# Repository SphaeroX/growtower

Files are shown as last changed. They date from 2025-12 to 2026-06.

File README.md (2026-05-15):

# GrowTower

A minimalist, vertical grow tower designed for home cannabis cultivation. This project focuses on space efficiency, ease of use, and effective odor control, making it perfect for beginners and small living spaces.

## Features

- **Vertical Grow System:** Maximizes vertical space usage.
- **Integrated Odor Control:** Features a custom-designed activated carbon filter housing.
- **Silent & Efficient Cooling:**  Uses a standard Arctic P14 generic PC fan for both airflow and cooling.
- **Web-based Control:** Control your GrowTower from any browser at `http://growtower.local` - no app required!
- **Automatic Light Timer:** Configurable 24h light schedule with web interface.
- **Minimalist Design:** clean aesthetics that blend into a modern home environment.
- **Beginner Friendly:**  Simple assembly and maintenance. Hard to make mistakes.
- **3D Printable:**  Most structural components are designed to be 3D printed.
- **Odor-Free Drying:** Convert the tower into a drying chamber after harvest using the included Dryer Module, utilizing the carbon filter.

## Gallery

| | | |
|:---:|:---:|:---:|
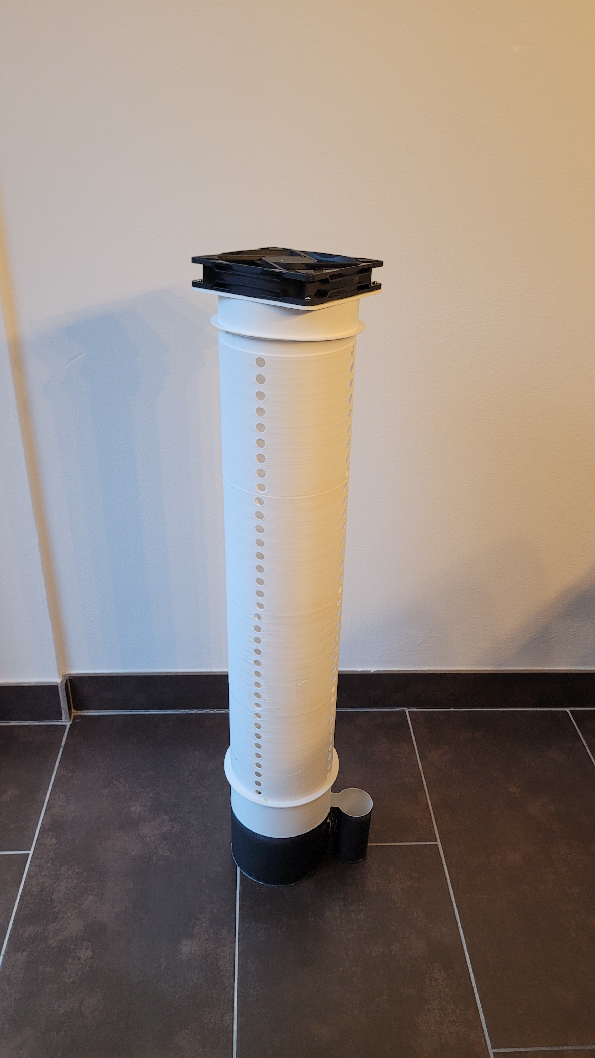
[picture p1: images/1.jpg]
View 1
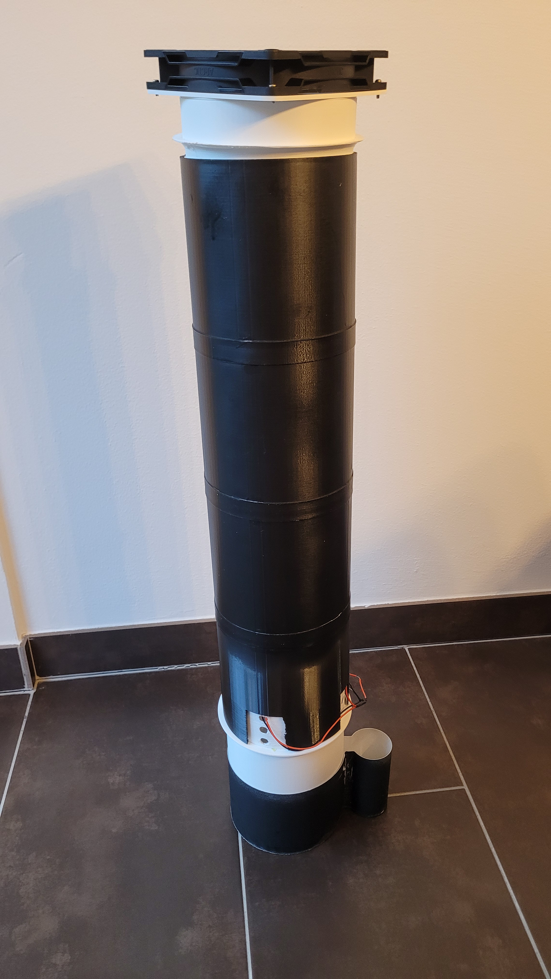
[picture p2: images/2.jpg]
View 2
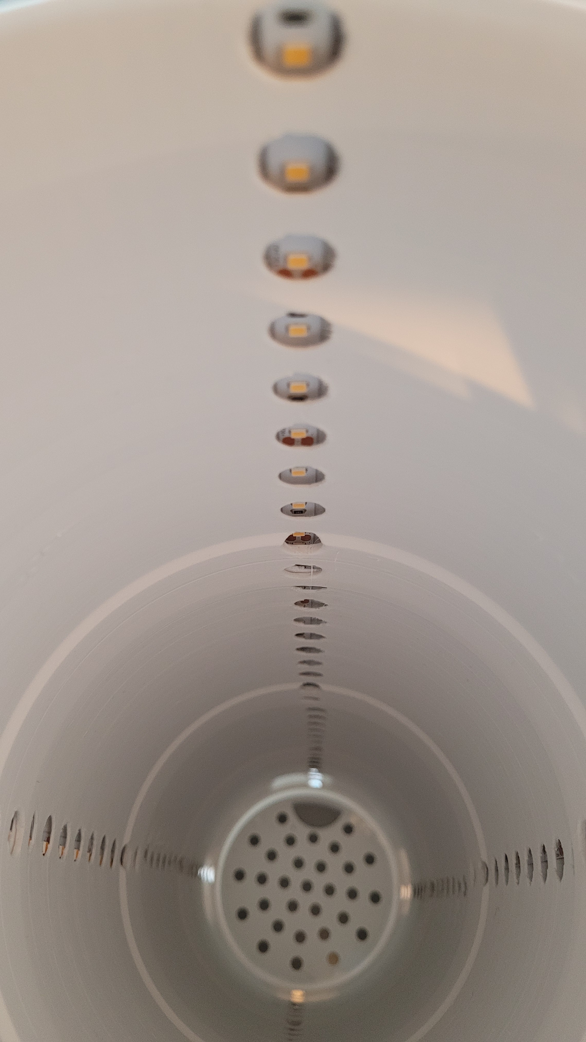
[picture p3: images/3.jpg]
View 3
|  |  |  |
| *Front View* | *With Light Chamber* | *Inside* |

### Controller & Electronics

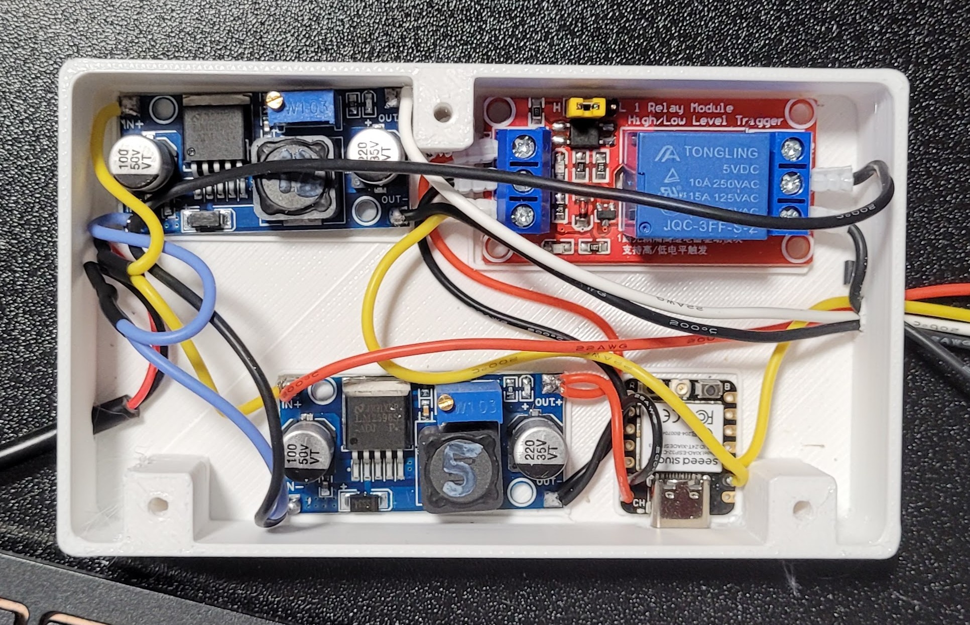
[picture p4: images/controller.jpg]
Controller

*Wired ESP32 Controller with Fan, Light Relay and Power Supply*

## How it Works

The GrowTower utilizes a forced-air system where the Arctic P14 fan pulls air through the tower, ensuring fresh CO2 for the plant and maintaining optimal temperatures. The air is then pushed through an activated carbon filter before exiting, neutralizing any odors. The vertical stacking design allows for modularity and easy height adjustment as the plant grows.

## Growing System

The GrowTower is designed for a **Full-Hydroponic Wick System** (using Pumice) or a **Semi-Hydroponic** setup. It utilizes passive irrigation to provide precise moisture control while maintaining high aeration for the roots.

For detailed, step-by-step instructions on the recommended **12/12 One-Bud method**, please refer to the [**GROW_GUIDE.md**](GROW_GUIDE.md).

## Drying after Harvest

With the included **Dryer Module** (STL), the GrowTower can easily be converted into an odor-free drying chamber. The module is simply inserted between the top Inner Shell and the Filter Housing. You can hang and tie your harvested plant directly to this module. The active carbon filter ensures that the entire drying process remains completely odorless.

## Getting Started

1. **Build your Tower:** See [BOM.md](BOM.md) for a full list of materials required.
2. **Follow the Grow Guide:** Use the [**GROW_GUIDE.md**](GROW_GUIDE.md) as your primary resource for successful cultivation. It contains the complete timeline, nutrient dosages, and substrate setup.
3. **Setup Controller:** Flash the ESP32 with the firmware from the `firmware/` directory. See [firmware/README.md](firmware/README.md) for details.

## Web Controller

The GrowTower includes a built-in web server for easy control via WiFi:

- **Access:** Open `http://growtower.local` in any browser after connecting to WiFi
- **Features:**
  - Real-time status dashboard (light, fan, timer)
  - Manual light control (ON/OFF)
  - PWM fan speed adjustment (0-100%) with configurable min/max range
  - 24-hour light timer with automatic scheduling
  - Configurable device hostname (e.g., `mytower.local`)
  - REST API for custom integrations

## 3D Printing Instructions

All STL files and detailed printing instructions are located in the [`stls/`](stls/) directory. This includes material recommendations, slicer settings, and assembly instructions. For detailed post-processing (light-proofing), see [`stls/README.md`](stls/README.md).

## Troubleshooting

### Light is blinking every second
If the main light is blinking in a 1-second interval, the controller **cannot synchronize the time** (no internet connection). Since the light timer depends on the current time, the controller enters this safety/warning mode.
- **Solution:**
  1. Connect your phone/PC to the WiFi network `GrowTower-Fallback`.
  2. Open `http://192.168.4.1` in your browser.
  3. Go to the settings and update your WiFi credentials (SSID & Password).
  4. Alternatively, you can manually set the current time via the API to enable offline operation.

### Cannot reach `growtower.local`
- Ensure you are on the same WiFi network as the GrowTower.
- Try accessing it via the IP address shown in the Serial Monitor.
- Some Windows systems require "Bonjour" or "iTunes" installed for `.local` (mDNS) support.

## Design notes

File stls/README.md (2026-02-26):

# 3D Printing Instructions

This directory contains all STL files for the GrowTower project.

## General Printing Recommendations & Materials

- **Main Material:** PETG White (highly recommended for the main body). The white color is crucial on the inside to maximize light reflection for the plant.
- **Exceptions (Black Material):** The Filter Components, Plant Pot, and Water Reservoir can and should be printed in **Black PETG** (or another dark opaque color). This prevents light from reaching the roots and water, which would otherwise encourage algae growth.
- **Light-Proofing (Crucial Step):** The white outer shell **must** be light-proofed from the outside. This is a critical physical requirement to prevent external light from disrupting the plant's light cycle (especially important for photoperiod strains in Grow #2). 
  - **Method 1 (Recommended):** Coat the fully assembled white outer shell from the outside using black spray foil / liquid rubber (e.g., PlastiDip). This ensures a light-tight seal by filling microscopic 3D printing gaps and offers better thermal elasticity.
  - **Method 2:** Wrap the outside tightly in a black, light-blocking foil or tape.
  - *Note:* The inside of the shell must remain white for maximum light reflection!
- **Nozzle:** 0.6mm recommended (faster printing, sufficient precision)
- **Support:** Generally not required for most parts

---

## Plant Pot Printing Instructions

The plant pot is 100mm tall. For optimal results without supports, the pot can either be printed **solid in one piece** or **cut at 49.7mm** and glued together:

### Option 1: Print Solid (Recommended for seamless result)
- Print the entire pot in one piece
- No cutting or gluing required
- May require minimal support for the rim

### Option 2: Cut and Glue (Saves support material)
1. **Cut the Pot:** In your slicer, use the cut tool to split the pot horizontally at **49.7mm** (exactly half).
2. **Print Both Parts:** 
   - **Upper part:** Print as oriented in the STL (no change needed)
   - **Lower part:** Rotate so the cut face sits flat on the print bed
3. **Glue Together:** After printing, glue the two halves together using super glue or epoxy. Align the seams carefully for a clean joint.

The cut method saves support material since each half prints flat without supports.

| | |
|:---:|:---:|
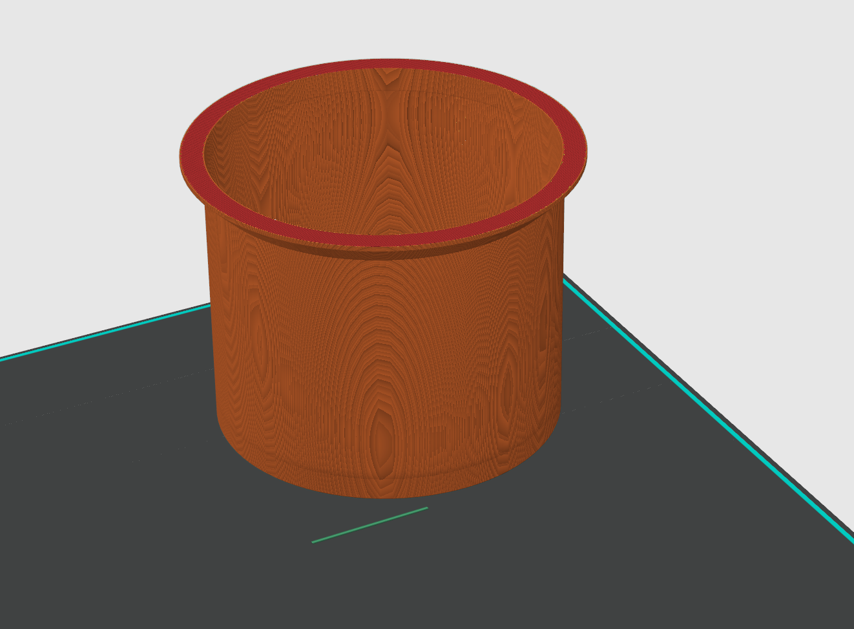
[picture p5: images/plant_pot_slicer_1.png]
Plant Pot Cut 1
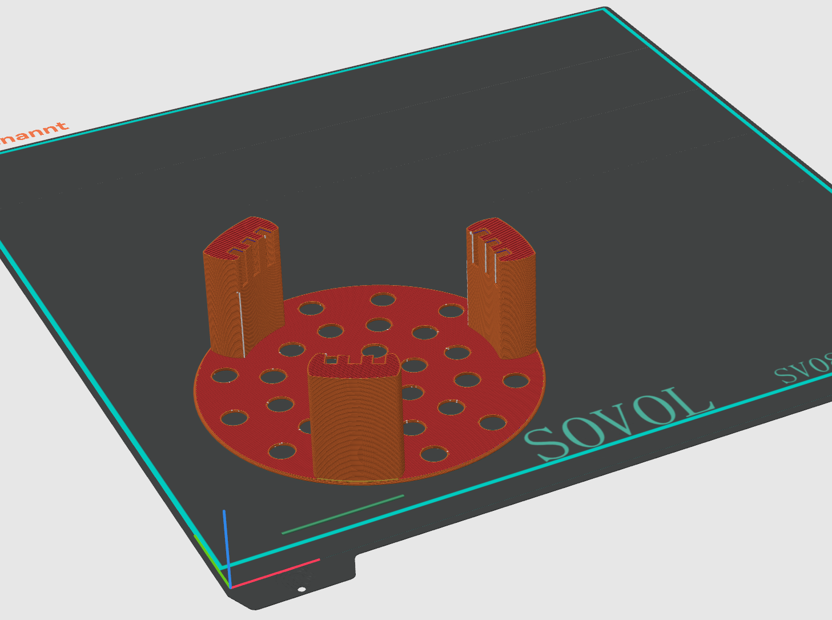
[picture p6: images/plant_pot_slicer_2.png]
Plant Pot Cut 2
|  |  |
| *Plant Pot Upper* | *Plant Pot Lower* |

---

## Internal Sieve Printing Instructions

The Internal Sieve model is intentionally designed to be "closed". To print it correctly:

1.  **Open the Sieve:** In your slicer, use a modifier to remove the top and bottom solid layers.
2.  **Create the Mesh:** Set the infill density to approximately **30%** and use a **Rectilinear** pattern. This generates the necessary mesh structure for the filter.

| | |
|:---:|:---:|
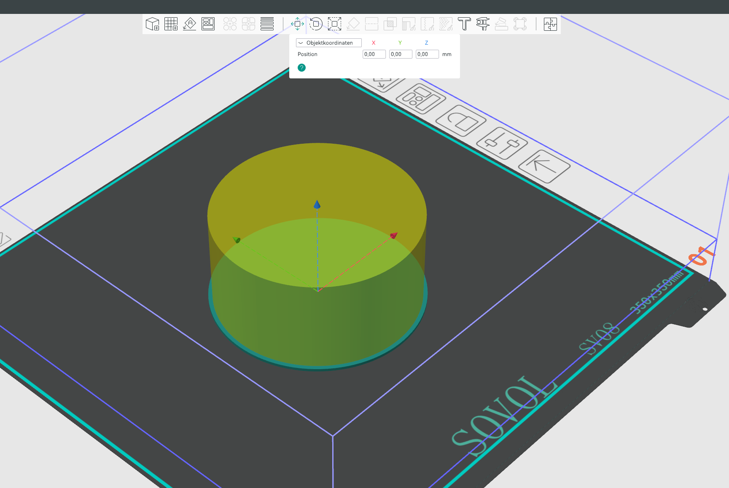
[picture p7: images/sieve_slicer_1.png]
Slicer View 1
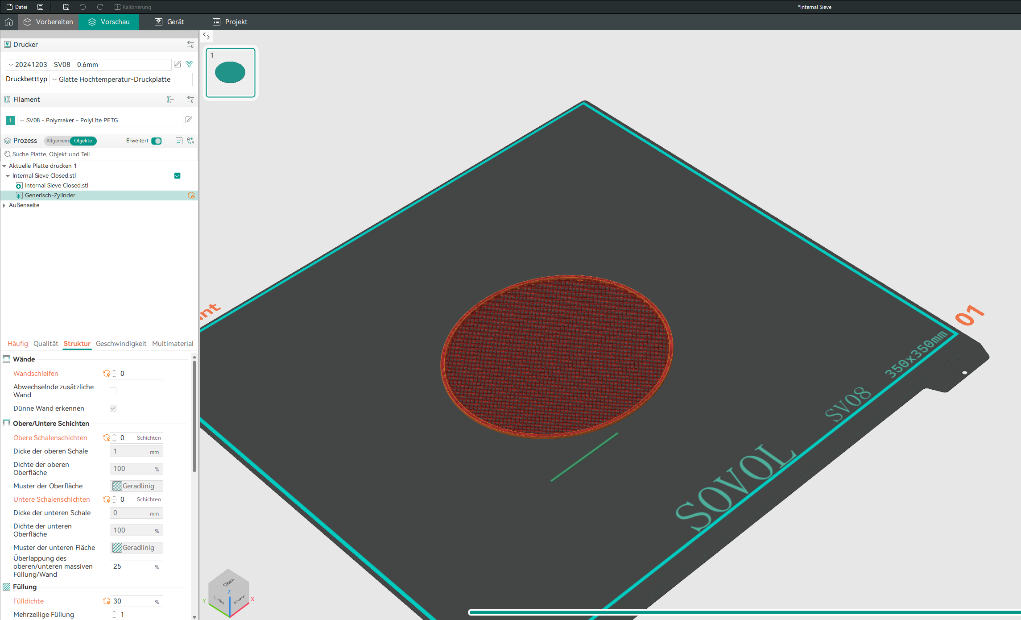
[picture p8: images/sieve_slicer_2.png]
Slicer View 2
|  |  |
| *Sieve View 1* | *Sieve View 2* |

---

## Reservoir 850 Vase Printing Instructions

**File:** `Reservoir 850 vase.stl`

For optimal printing results and watertightness, use these settings:

1. **Vase Mode:** Enable "Spiralize" or "Vase Mode" in your slicer.
2. **Bottom Layers:** Use at least **4 bottom layers** for a stable and leak-proof base.
3. **Pattern Design:** Ensure the upper pattern differs from the lower pattern to create a distinct transition and visual appeal.
4. **Layer Height:** Use a **small layer height** (e.g., 0.1-0.2mm) to ensure the print is watertight.
5. **Flow Rate:** Increase flow rate by at least **5%** compared to your standard settings for better layer adhesion and watertightness.
6. **Ironing:** Enable ironing to re-weld the top layer for a smoother and more sealed surface.
7. **Infill/Wall Overlap (OrcaSlicer):** Set BOTH values to **40% to 50%**:
   - `InfillWall-Overlap`
   - `infill-wall-overlap`

### Troubleshooting Leaks

- **Water Test:** Always perform a water test before using the reservoir to check for leaks.
- **Common Issue:** Pay special attention to the transition from the bottom to the walls, as this is where leaks most commonly occur.
- **Repair:** If leaks are found at the bottom-wall transition, they can often be fixed by welding the spots with a soldering iron. Don't give up - somehow it can always be made watertight!

## Dryer Module Printing Instructions

The Dryer Module (Trocknungsmodul) is an optional insert used after harvest. It allows you to hang the harvested plant inside the tower for drying.

- **Function:** Fastening points are provided to tie the plant securely for drying.
- **Placement:** Insert the module simply between the top Inner Shell and the Filter Housing.
- **Printing:** Standard settings (15-20% infill). Can be printed in any color, though Black or White PETG is recommended to match the tower.
- **Benefit:** By drying inside the GrowTower, the active carbon filter continues to neutralize all odors during the drying process.

---

## Other Parts

The remaining parts (Inner Shell, Outer Shell, Outer Shell Bottom, Shell Connector, Filter Housing, Fan Adapter) can be printed with standard settings:

- **Infill:** 15-20%
- **Supports:** Not required
- **Orientation:** Print as oriented in the STL file

### Outer Shell Assembly

The outer shell consists of **3x Outer Shell** + **1x Outer Shell Bottom**, connected with **3x Shell Connector**:

**Printing Options:**
- **Standard Print:** Print with normal settings (15-20% infill, walls as normal)
- **Vase Mode (Faster):** Print in vase/spiralize mode for faster printing. Note: You'll need to orient the LED strips carefully after printing to ensure even light distribution. When printed in vase mode, a small bump remains visible on the inside - use this as your orientation marker for LED strip alignment.

| | |
|:---:|:---:|
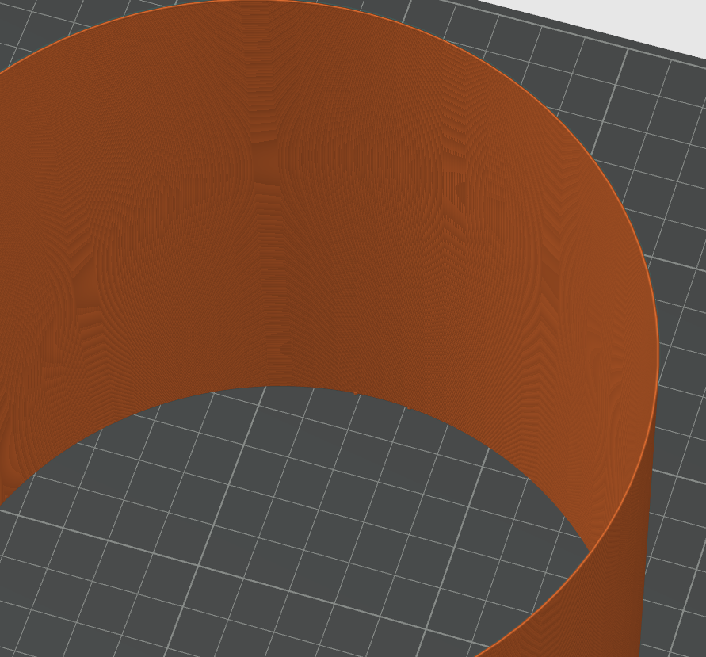
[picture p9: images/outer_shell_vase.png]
Outer Shell Vase
|  | *Visible bump for LED orientation* |

**Assembly:**
1. **Print:** Print 3x Outer Shell and 1x Outer Shell Bottom, plus 3x Shell Connector
2. **First Connector:** 
   - Apply a small amount of glue to the connector and position it on the first Outer Shell section
   - Apply glue all around the connector where it overlaps with the shell
   - Push the connector down so it slides onto the glue - this ensures the 50% overlap
3. **First Shell Section Complete:** Let the glue fully cure before continuing (otherwise it will slip)
4. **Add Second Shell:**
   - Apply a small amount of glue to the connector and pre-mount the next Outer Shell section
   - Apply glue all around the connector
   - Push the second shell down onto the connector
5. **Repeat:** Continue the same process for all remaining Outer Shell sections
6. **Attach Bottom:** Finally, attach the Outer Shell Bottom at the base using the same method

The Shell Connector is a ring that overlaps 50% with each shell, creating a secure slip-fit joint between sections.

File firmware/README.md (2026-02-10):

# GrowTower Firmware

This directory contains the ESP32 Arduino-based firmware for the GrowTower, designed for the **Seeed Studio XIAO ESP32C3** (configured as `seeed_xiao_esp32c3` in PlatformIO).

## Features

- **Web-based Control**: Access the controller via any web browser at `http://growtower.local`
- **REST API**: HTTP endpoints for all control functions
- **mDNS Support**: Automatic discovery via `*.local` domain (configurable hostname)
- **Real-time Status**: Live updates of system state in the web interface
- **OTA Updates**: Over-the-air firmware updates via PlatformIO
- **Automatic Timer**: Light scheduling with configurable on/off hours
- **Fan Control**: PWM-based speed control with configurable min/max range
- **Persistent Settings**: All configuration stored in flash memory

## Prerequisites

- **VS Code** with **PlatformIO** extension installed.
- OR **PlatformIO Core** (CLI) installed.

## Configuration

Settings are managed via a local `.env` file (ensuring credentials are not committed to git).

### 1. WiFi Credentials (.env)

You **MUST** create a file named `.env` in the `firmware/` directory. This file is used to generate `secrets.h` before every build.

**Example `firmware/.env` content:**
```ini
WIFI_SSID="YourWiFiName"
WIFI_PASS="YourSuperSecretPassword"
```
*Note: This file is ignored by git.*

### 2. Pin Definitions

Pin definitions are located in `src/main.cpp`.

By default:
- **Light Relay**: GPIO 1 (D1)
- **Fan PWM**: GPIO 4 (D2)

### 3. Hostname Configuration

The default hostname is `growtower`. You can change it via:
- **Web Interface**: Settings → Device Name
- **Serial Command**: `HOST <newname>`

After changing, the device will restart and be available at `http://<newname>.local`

## Building and Flashing

Open your terminal in this directory (`growtower/firmware`).

### 1. Build

Compiles the firmware:

```powershell
pio run
```

### 2. Flash (USB)

Uploads firmware via USB:

```powershell
pio run -t upload
```

*Note: If the upload fails, ensure the device is in bootloader mode (hold BOOT, press RESET, release BOOT).*

### 3. Flash (OTA - Over The Air)

Uploads firmware wirelessly (after initial USB flash):

```powershell
pio run -t upload -e main_ota
```

Or specify the hostname/IP:
```powershell
pio run -t upload --upload-port growtower.local
```

### 4. Monitor

Opens the serial monitor for debugging:

```powershell
pio device monitor
```
*Note: Exit with `Ctrl+C`.*

## Web Interface

Once connected to WiFi, open your browser and navigate to:

```
http://growtower.local
```

### Features

- **Dashboard**: Real-time status of light, fan, timer settings
- **Light Control**: Turn light ON/OFF manually
- **Fan Control**: Adjust speed (0-100%) and set min/max range
- **Timer Settings**: Configure automatic light schedule (24h format)
- **Network Settings**: Change device hostname (requires restart)

The interface automatically updates every 2 seconds and is optimized for both desktop and mobile devices.

## REST API

All functions are accessible via HTTP GET requests:

| Endpoint | Parameters | Description |
|---|---|---|
| `GET /api/status` | - | Returns JSON with all current values |
| `GET /api/light` | `state=0\|1` | Turn light OFF (0) or ON (1) |
| `GET /api/fan` | `speed=0-100` | Set fan speed percentage |
| `GET /api/fanrange` | `min=0-100&max=0-100` | Set fan min/max range |
| `GET /api/timer` | `on=0-23&off=0-23` | Set light timer hours |
| `GET /api/hostname` | `name=<hostname>` | Change hostname (reboots) |

### Example API Responses

**Status Request:**
```bash
curl http://growtower.local/api/status
```

**Response:**
```json
{
  "light": true,
  "fan": 30,
  "fanMin": 0,
  "fanMax": 100,
  "lightOn": 18,
  "lightOff": 14,
  "hostname": "growtower",
  "ip": "192.168.1.100",
  "wifiConnected": true,
  "hasTime": true,
  "currentTime": "14:30:25"
}
```

## Serial Console Commands

You can also control the device via serial monitor:

| Command | Description | Example |
|---|---|---|
| `ON` | Turn light ON | `ON` |
| `OFF` | Turn light OFF | `OFF` |
| `FAN <0-100>` | Set fan speed | `FAN 50` |
| `FANMIN <0-100>` | Set minimum fan speed | `FANMIN 10` |
| `FANMAX <0-100>` | Set maximum fan speed | `FANMAX 90` |
| `LIGHTON <0-23>` | Set light ON hour | `LIGHTON 18` |
| `LIGHTOFF <0-23>` | Set light OFF hour | `LIGHTOFF 14` |
| `HOST <name>` | Set device hostname | `HOST mytower` |
| `TIME` | Show current time | `TIME` |
| `STATUS` | Show full status | `STATUS` |
| `RESET` | Reset all settings | `RESET` |
| `HELP` | Show command list | `HELP` |

## Default Settings

After first flash or reset:

- **Light**: OFF
- **Fan Speed**: 30%
- **Fan Range**: 0% - 100%
- **Light Timer**: 18:00 ON → 14:00 OFF
- **Hostname**: growtower

## Troubleshooting

### Cannot access growtower.local

1. Ensure your device is on the same network as the ESP32
2. Try accessing via IP address (check serial monitor for IP)
3. On Windows: Install Bonjour Print Services or iTunes (for mDNS support)
4. On Linux: Ensure `avahi-daemon` is running
5. Some routers may block mDNS - use IP address instead

### Web interface not loading

1. Check WiFi connection in serial monitor
2. Verify the ESP32 got an IP address
3. Try clearing browser cache
4. Check firewall settings

### Upload fails

1. **USB Upload**: Check COM port with `pio device list`
2. **OTA Upload**: Ensure device is online and hostname resolves
3. **Bootloader Mode**: For first flash:
   - Hold `BOOT` button
   - Press and release `RESET`
   - Release `BOOT`
   - Try uploading again

### Settings not persisting

Ensure the ESP32 has enough flash space and isn't being reset during write operations.

## Technical Details

- **Framework**: Arduino (PlatformIO)
- **Platform**: ESP32-C3 (Seeed Studio XIAO)
- **Web Server**: ESPAsyncWebServer
- **mDNS**: ESPmDNS
- **Storage**: Preferences (NVS)
- **OTA**: ArduinoOTA

## Project Structure

```
firmware/
├── src/
│   └── main.cpp          # Main firmware code
├── include/
│   └── secrets.h         # Auto-generated from .env
├── platformio.ini        # PlatformIO configuration
├── .env                  # Your WiFi credentials (gitignored)
└── README.md            # This file
```

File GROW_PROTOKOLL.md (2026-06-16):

# GrowTower: Protocol & Logbook

This protocol serves as a printable logbook to document your current grow using the **12/12 One-Bud method**. Enter the dates and check off the completed steps.

**Start Date (Germination):** ________________________  
**Strain:** ________________________  
**Stated Flowering Time:** ________________________  

---

## Phase Protocol

| Phase / Timeline | Day | Date | Action (Short Format) | Completed / Notes |
| :--- | :--- | :--- | :--- | :--- |
| **Phase 0:**<br>Germination | **Day 0** | | - Soak seed in water for 24-36h<br>- Plant seed, water once with 30ml pH-adjusted water<br>- Light: 18/6-20/4 (see Grow Guide), Fan: 0%<br>- Daily: 2x 3ml via pipette directly to seed spot | |
| **Week 1:**<br>Establishment | **Day 1 - 7** | | - Water only drop by drop via pipette if extremely dry<br>- Fan: 30% | |
| **Week 2:**<br>First Flush | **Day 8 - 10** | | - 1x full watering (800ml pH-adjusted water) from above (until runoff/drain)<br>- Afterwards **do not water at all**, let substrate dry! | |
| **Week 3:**<br>Reservoir | **Day 15 - 21**  | | - **Switch light to 12/12!**<br>- Pour out old flush water completely first!<br>- Fill reservoir to 20-30% with pure, pH-adjusted water<br>- **Never water from above again!**<br>- Add 50% Hy-Pro Terra dose (~2.0ml per 800ml) — soil nest is depleted, pumice needs feeding | |
| **Week 4-5:**<br>Stretch | **Day 22 - 35**  | | - 75-100% Hy-Pro Terra dose in reservoir (~3.0-4.0ml per 800ml)<br>- Ramp from 3.0ml to 4.0ml by end of phase<br>- Refill reservoir regularly<br>- Watch out for first white hairs (pistils) | |
| **Flowering:**<br>Flower Day 1 | **ca. Day 30** | | - First white hairs spotted = Flower Day 1!<br>- Note the exact date for Flower Day 1 below | |
| **Flowering Phase:**<br>Full Bloom | **FD 1 to End**  | | - Fan: 46%<br>- 100% Hy-Pro Terra: ~4.0ml fertilizer + ~2.3ml pH-Down per 800ml<br>- Optional: 125% peak boost (~5.0ml) mid-flower if no tip burn | |
| **Flushing:**<br>Flush | **Last 14 Days** | | - Stop all fertilizer 10-14 days before harvest<br>- Fill reservoir only with pure, pH-adjusted water | |
| **Harvest** | **-** | | - Cut, dry & cure | |

---

## Important Dates & Milestones

* **Day 1 (Seedling emerges):** ________________________
* **Day 8 (First Flush completed):** ________________________
* **Flower Day 1 (First pistils visible):** ________________________
* **Planned Harvest Date (FD 1 + Flowering Time):** ________________________
* **Start Flushing Phase (-14 days before harvest):** ________________________

---

## Logbook: Nutrient Solution & Measurements

*Rule:* Never let nutrient solution sit in the reservoir for more than 7-10 days (maximum 14 days) to prevent root rot!  
*Recipe (800ml):* ~4.0ml Hy-Pro Terra + ~2.3ml pH-Down (Target pH: 5.8). Add CalMag (0.5-1.0ml/L) every 3rd refill.

| Date | Action (Refill / Change) | Amount Water (ml) | Amount Fertilizer (ml) | pH Measured | Notes (Plant Health / Appearance) |
| :--- | :--- | :--- | :--- | :--- | :--- |
| | | | | | |
| | | | | | |
| | | | | | |
| | | | | | |
| | | | | | |
| | | | | | |
| | | | | | |
| | | | | | |
| | | | | | |
| | | | | | |
| | | | | | |
| | | | | | |
| | | | | | |
| | | | | | |
| | | | | | |
| | | | | | |

---
*Reminder: Once the wick system (reservoir) is active, never water from above again!*

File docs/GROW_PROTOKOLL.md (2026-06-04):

# GrowTower: Protocol & Logbook

This protocol serves as a printable logbook to document your current grow using the **12/12 One-Bud method**. Enter the dates and check off the completed steps.

**Start Date (Germination):** ________________________  
**Strain:** ________________________  
**Stated Flowering Time:** ________________________  

---

## Phase Protocol

| Phase / Timeline | Day | Date | Action (Short Format) | Completed / Notes |
| :--- | :--- | :--- | :--- | :--- |
| **Phase 0:**<br>Germination | **Day 0** | | - Soak seed in water for 24-36h<br>- Plant seed, water once with 30ml pH-adjusted water<br>- Light: 12/12, Fan: 0%<br>- Daily: 2x 3ml via pipette directly to seed spot | |
| **Week 1:**<br>Establishment | **Day 1 - 7** | | - Water only drop by drop via pipette if extremely dry<br>- Fan: 30% | |
| **Week 2:**<br>First Flush | **Day 8 - 10** | | - 1x full watering (800ml pH-adjusted water) from above (until runoff/drain)<br>- Afterwards **do not water at all**, let substrate dry! | |
| **Week 3:**<br>Reservoir | **Day 15 - 21** | | - Pour out old flush water completely first!<br>- Fill reservoir to 20-30% with pure, pH-adjusted water<br>- **Never water from above again!**<br>- Add 25% fertilizer dose if leaves turn light green | |
| **Week 4-5:**<br>Stretch | **Day 22 - 35** | | - 50% fertilizer dose in reservoir (~0.9ml per 800ml)<br>- Refill reservoir regularly<br>- Watch out for first white hairs (pistils) | |
| **Flowering:**<br>Flower Day 1 | **ca. Day 30** | | - First white hairs spotted = Flower Day 1!<br>- Note the exact date for Flower Day 1 below | |
| **Flowering Phase:**<br>Full Bloom | **FD 1 to End** | | - Fan: 46%<br>- 100% fertilizer: ~1.8ml fertilizer + ~2.3ml pH-Down per 800ml | |
| **Flushing:**<br>Flush | **Last 14 Days** | | - Stop all fertilizer 10-14 days before harvest<br>- Fill reservoir only with pure, pH-adjusted water | |
| **Harvest** | **-** | | - Cut, dry & cure | |

---

## Important Dates & Milestones

* **Day 1 (Seedling emerges):** ________________________
* **Day 8 (First Flush completed):** ________________________
* **Flower Day 1 (First pistils visible):** ________________________
* **Planned Harvest Date (FD 1 + Flowering Time):** ________________________
* **Start Flushing Phase (-14 days before harvest):** ________________________

---

## Logbook: Nutrient Solution & Measurements

*Rule:* Never let nutrient solution sit in the reservoir for more than 7-10 days (maximum 14 days) to prevent root rot!  
*Recipe (800ml):* ~1.8ml Grow Bloom + ~2.3ml pH-Down (Target pH: 5.8).

| Date | Action (Refill / Change) | Amount Water (ml) | Amount Fertilizer (ml) | pH Measured | Notes (Plant Health / Appearance) |
| :--- | :--- | :--- | :--- | :--- | :--- |
| | | | | | |
| | | | | | |
| | | | | | |
| | | | | | |
| | | | | | |
| | | | | | |
| | | | | | |
| | | | | | |
| | | | | | |
| | | | | | |
| | | | | | |
| | | | | | |
| | | | | | |
| | | | | | |
| | | | | | |
| | | | | | |

---
*Reminder: Once the wick system (reservoir) is active, never water from above again!*

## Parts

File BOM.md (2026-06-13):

# Bill of Materials (BOM)

Here is the list of parts required to build the GrowTower.

## Hardware & Electronics

| Component | Quantity | Description | Price (Est.) | Source | Notes |
| :--- | :---: | :--- | :---: | :--- | :--- |
| **Fan** | 1 | Arctic P14 PWM PST (140mm) | 9.99€ | Amazon | High Static Pressure Fan. |
| **Power Supply** | 1 | 24V DC, 2A | 13.00€ | Amazon | Power supply for LEDs and Fan. |
| **Step-Down Module** | 2 | DC-DC Buck Converter | ~3.40€ | Amazon | Calculated from 5-pack (8.40€). Used to lower voltage for fan/controller if needed. |
| **Microcontroller** | 1 | Seed Studio XIAO ESP32 C6 | 5.00€ | AliExpress | Control unit (WiFi/BLE). |
| **Relay Module** | 1 | Arduino Relay Module (1-Channel) | 1.70€ | AliExpress | To switch high voltage components (if needed). |
| **Wiring** | - | 22 AWG Silicone Wire (0.32mm²) | ~5.00€ | AliExpress | Soft silicone insulation recommended. |
| **Screws & Nuts** | 4x | M3 x 10-15mm + Nuts | ~2.00€ | Hardware Store | For mounting components. |
| **Grow Light** | 1 | Auxmer Low Power 2835 LED Strip | 27.00€ | AliExpress | 120 LEDs/m, 4000K Color Temp. Price includes shipping. |

## Consumables

| Component | Quantity | Description | Price (Est.) | Notes |
| :--- | :---: | :--- | :---: | :--- |
| **Filament** | ~1 kg | PETG White | 22.00€ | Recommended for durability and light reflection. |
| **Activated Carbon** | 1 kg | Pellets (3-4mm), CTC > 65% | 16.80€ | eBay (helo24) | High absorption. |
| **Black Spray Foil** | 1 Can | Liquid Rubber / PlastiDip | ~15.00€ | Amazon/Hardware Store | For perfect light blocking and gap filling. |
| **Pipettes** | 5-10 pcs | 3ml Plastic Pipettes | ~3.00€ | Amazon/Pharmacy | Essential for precise dosage of pH-Down and fertilizer. |

## Growing Mediums & Nutrients

These materials depend on the specific grow method being tested (Soil vs. Hydroponic).

| Component | Description | Price (Est.) | Notes |
| :--- | :--- | :---: | :--- |
| **Composana Soil** | Qualitätsblumenerde | ~12.00€ | Small "earth nest" at top of pot for germination and initial seedling nutrients. Only ~200ml needed per grow. |
| **Pumice (Bimsstein)** | Compo Sana Granulat | ~9.00€ | Main growing medium (inert, no CEC). Excellent aeration and wicking. Reusable indefinitely — rinse between grows. |
| **Wick System (Dochte)** | Nylon or Cotton Wicks | ~5.00€ | Passive irrigation for reservoir setups. |
| **Fertilizer** | Hy-Pro Terra (Single Base) | ~15.00€ | Complete 1-component mineral nutrient (NPK 2-5-5). For pumice: 50% start → 75-100% stretch → 100% flower → optional 125% peak. ~2.0–5.0ml per 800ml. Use a pipette for precision. |
| **pH-Down** | Canna pH- Bloom (Phosphoric Acid) | ~12.00€ | Critical for Hydro and Soil. Recommended: ~2.3ml per 800ml water (depends on local tap water). Use a pipette. |
| **CalMag** | Hy-Pro Cal-Mag (or equivalent) | ~12.00€ | Prevents Ca/Mg deficiencies in reused inert substrate. Add 0.5–1.0 ml/L to every 3rd reservoir refill. |  
## 3D Printed Parts

Most parts need to be printed in **PETG White** to ensure maximum light reflection inside the tower. However, to prevent light leaks and algae, specific parts (Filter, Plant Pot, Reservoir) should be printed in black, and the white outer shell must be post-processed to be light-proof from the outside. For detailed printing instructions and color choices, see [`stls/README.md`](stls/README.md).

The modular design consists of:

### Base & Reservoir
- **Plant Pot:** The bottom container for the plant.
- **Reservoir/Overpot:** Outer water container/shell that holds the pot.

### Shell Assembly
The 4-level structure is built from the following parts:
- **Inner Shell (4x):** Holds the plant/roots.
- **Outer Shell Bottom (1x):** The base segment of the outer shell.
- **Outer Shell (3x):** Standard segments stacked on top of the bottom shell.
- **Shell Connector (3x):** Outer rings used to connect the shell segments (glued).

### Filter Assembly (Top)
- **Filter Housing:** Container for the activated carbon.
- **Internal Sieve:** Sieve insert for inside the filter housing.
- **Fan Adapter:** Connects the 140mm fan to the filter housing.

### Accessories
- **Dryer Module:** An optional insert placed between the top Inner Shell and the Filter Housing. Used to hang and tie the plant for drying within the tower after harvest, utilizing the tower's active carbon filter for odor control.

*Note: STL files are located in the `stls/` directory (placeholder).*

## Tools Required

- **3D Printer:** (or access to one)
- **Soldering Iron:** For electrical connections.
- **Side Cutters / Wire Strippers:** For preparing cables.
- **Screwdriver:** For M3 screws.

## Total Estimated Cost

- **GrowTower Construction:** Approx. **~125.00€** (Hardware, Electronics, Filament, and Filter materials).
- **Consumables & Growing:** Approx. **~50.00€** (Pumice, Soil, Fertilizer, pH-Down, and Pipettes).

**Total Project Estimate: ~175.00€** (excluding seeds).

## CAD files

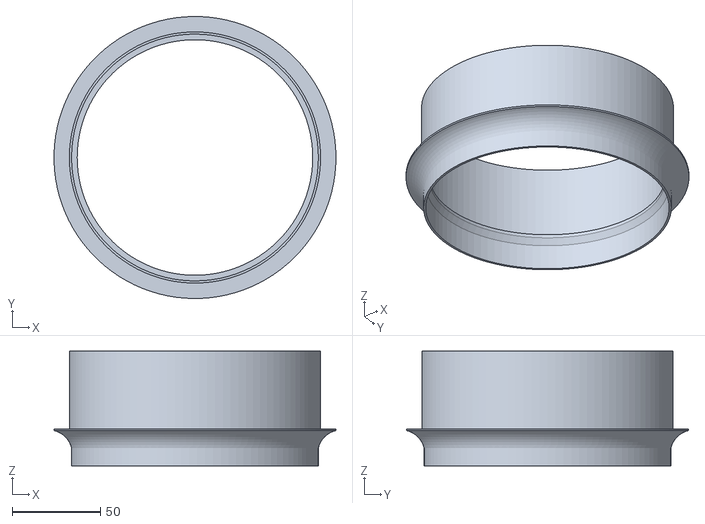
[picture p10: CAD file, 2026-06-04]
stls/Filter Housing.stl
160.0 x 160.0 x 65.0

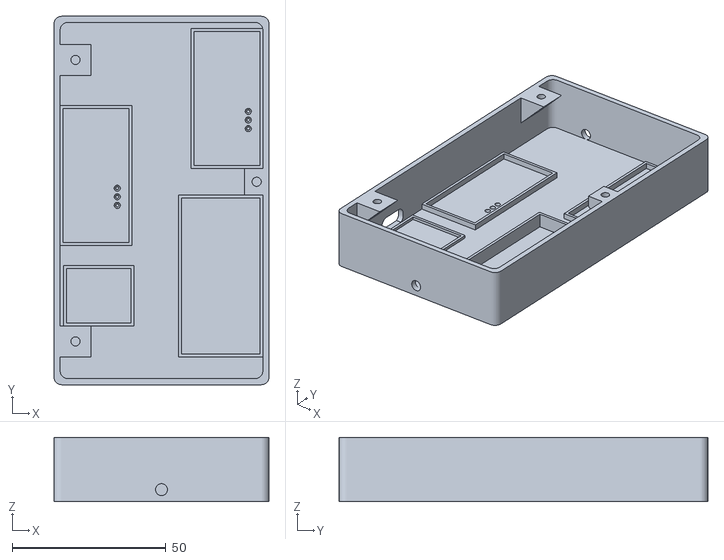
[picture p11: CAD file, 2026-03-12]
stls/Controller Case.stl
70.0 x 120.0 x 21.0

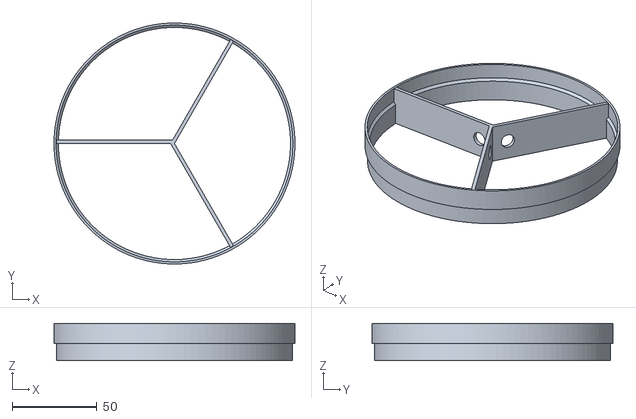
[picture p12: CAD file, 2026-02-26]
stls/Dryer Module.stl
142.5 x 142.5 x 22.0

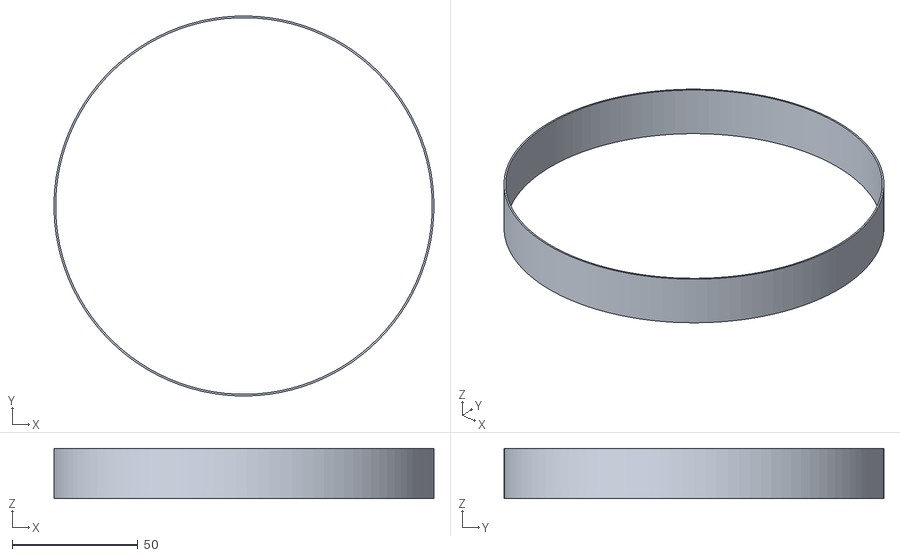
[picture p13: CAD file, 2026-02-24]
stls/Shell Connector.stl
150.9 x 150.9 x 20.0

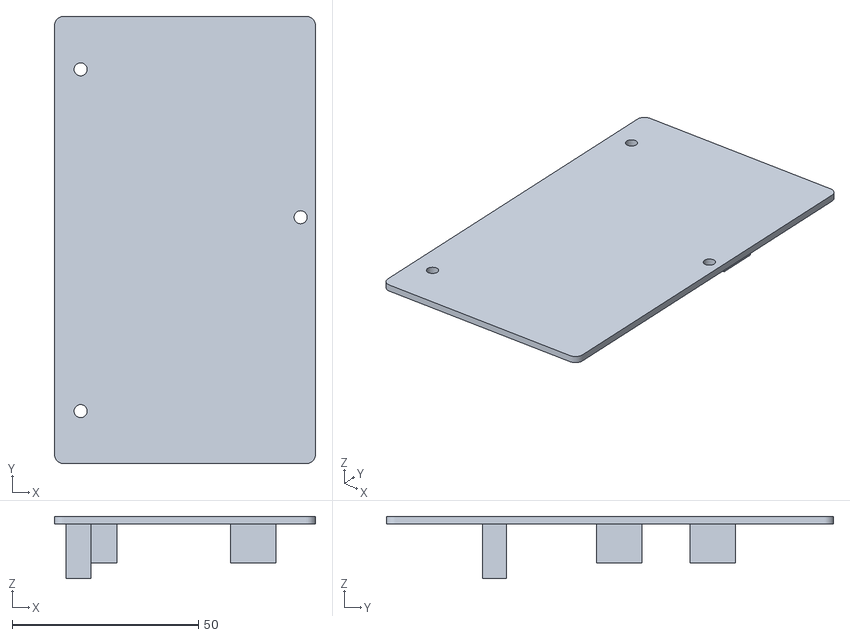
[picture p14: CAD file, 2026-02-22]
stls/Controller Cover.stl
70.0 x 120.0 x 16.7

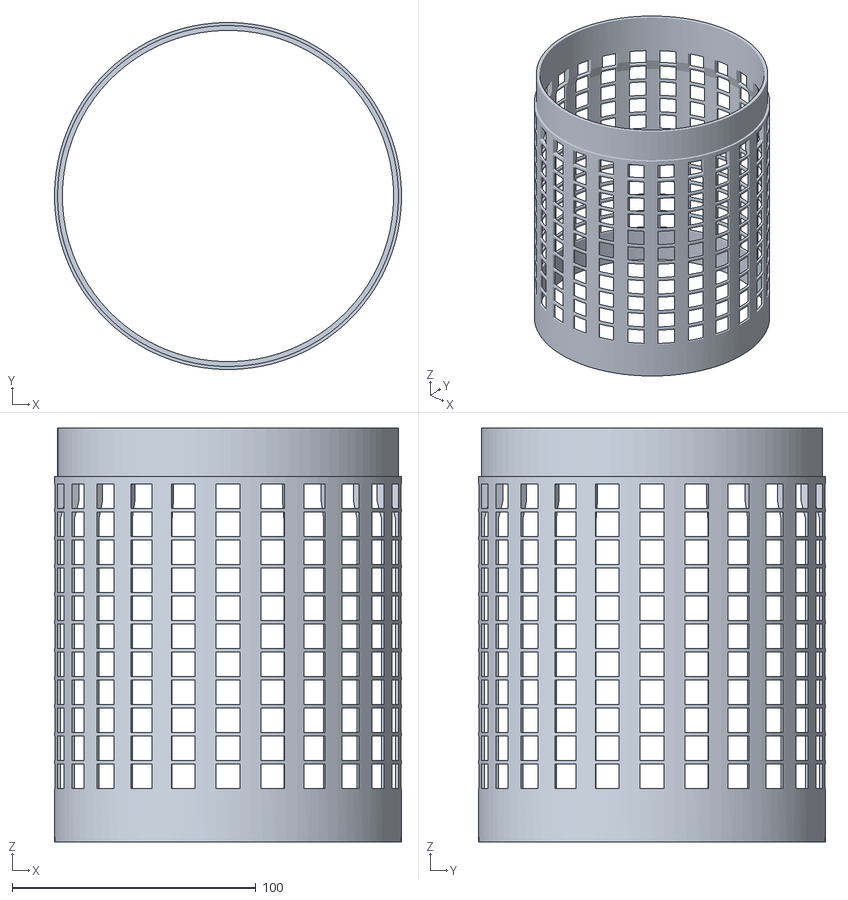
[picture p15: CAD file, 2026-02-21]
stls/Inner Shell.stl
142.5 x 142.5 x 170.0

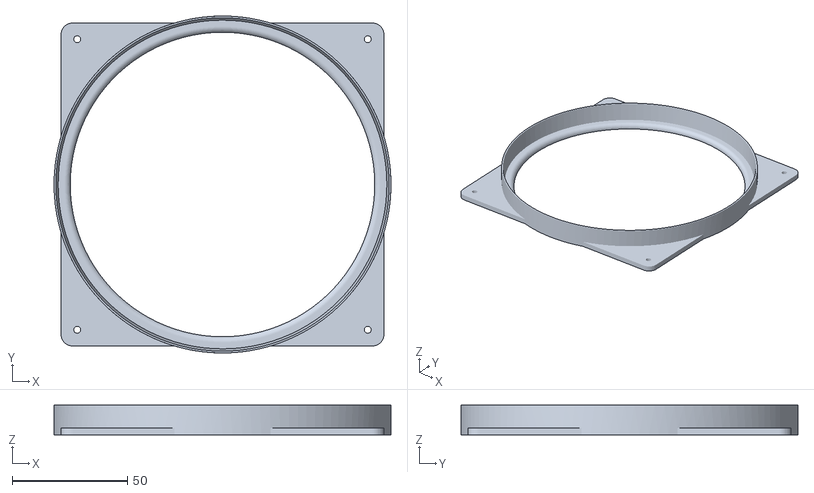
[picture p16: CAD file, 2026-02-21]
stls/Fan Adapter.stl
146.1 x 146.1 x 13.0

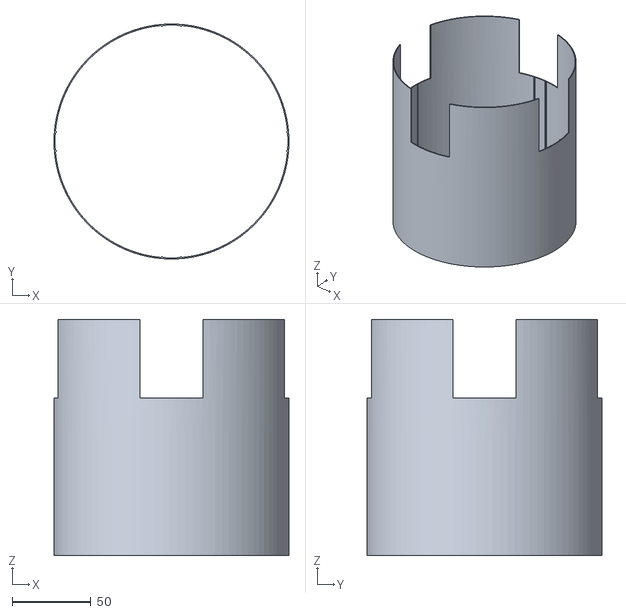
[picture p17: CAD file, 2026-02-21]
stls/Outer Shell Bottom.stl
149.3 x 149.3 x 150.0

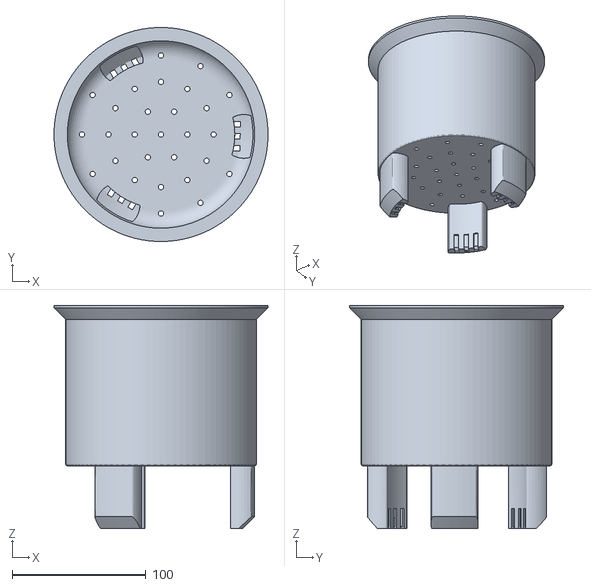
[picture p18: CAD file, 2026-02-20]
stls/plant pot.stl
160.0 x 160.0 x 167.0

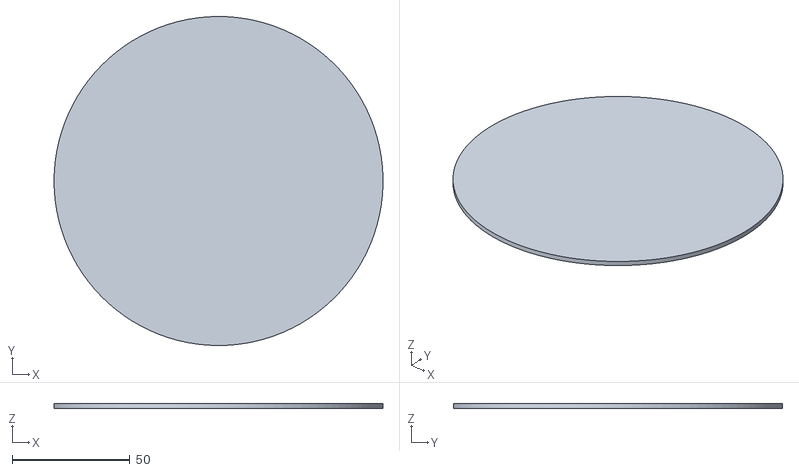
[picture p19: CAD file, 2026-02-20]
stls/Internal Sieve.stl
139.5 x 139.5 x 2.00

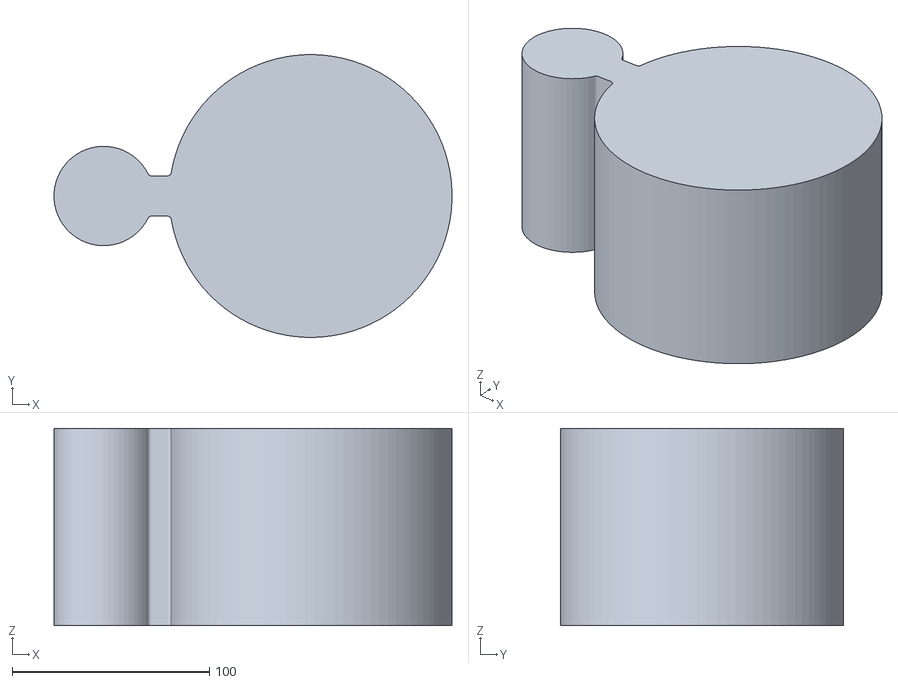
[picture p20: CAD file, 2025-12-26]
stls/Reservoir 850 vase.stl
201.8 x 143.3 x 100.0

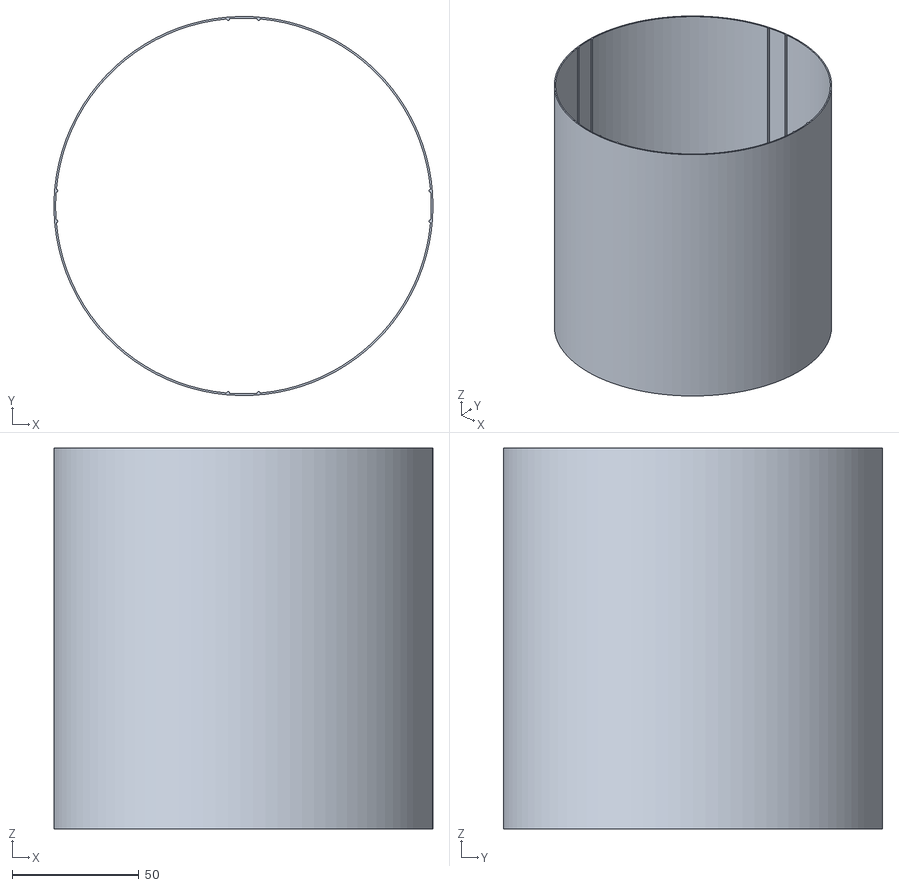
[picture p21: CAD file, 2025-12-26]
stls/Outer Shell.stl
149.3 x 149.3 x 150.0

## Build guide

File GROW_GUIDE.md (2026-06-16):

# GrowTower: The Ultimate Guide (12/12 One-Bud Method)

This guide describes how to grow in the GrowTower using a full-hydroponic wick system. The method is optimized for the **12/12 One-Bud technique**, which skips the vegetative phase to grow a single, large main bud.

## 1. Preparation & Materials

### Substrate & Wick System
*   **Main Medium:** Pumice (Pumice granules, e.g., from Compo Sana).
*   **Seed Container:** A small indentation at the top center is filled with **Compo Sana Quality Potting Soil**. This "earth nest" gives the seed a place to germinate, form its first roots, and access initial nutrients (like CalMag) naturally — no early fertilizer needed.
*   **Wicks:** Three wicks in total. One wick is pulled into **each of the three feet** of the plant pot.
*   **Installation:** The wicks must reach the bottom of the reservoir and be guided spirally upwards through the pumice inside the pot, ending directly at/under the soil nest.

### Preparing the Earth Nest (Erde-Nest)
The soil nest is the only organic component in an otherwise fully inert system. Get this right — it's the seed's first home.
1.  **Fill the pot with pumice** up to ~3 cm below the rim. Level the surface.
2.  **Create a small bowl** in the center: press a depression ~5 cm wide × 3 cm deep into the pumice. This is your nest cavity.
3.  **Ensure wick contact:** All three wicks should be visible at the bottom of the cavity, spiraling up through the pumice. If not, gently pull the wick ends into the cavity with tweezers.
4.  **Add soil:** Fill the cavity with **Compo Sana Quality Potting Soil** (~50–70 ml, about a small handful). Do not compress — keep it fluffy.
5.  **Pre-water the nest:** Saturate the soil with **~20 ml of pH-adjusted water (pH 5.8)**. Let it absorb fully. This pre-charges the wicks and ensures moisture reaches the seed immediately after planting.
6.  **Plant the seed:** Push the seed ~0.5–1 cm deep into the moist soil, cover lightly. See Phase 0 for the full germination procedure.

### Nutrient Solution (The 800ml Recipe)
Precision is key. Always use a **pipette** for dosing in the 800ml reservoir.
*   **Fertilizer:** **Hy-Pro Terra** — a complete 1-component nutrient for both growth and flowering. NPK 2-5-5, mineral-based for immediate availability.
    *   *Note for pumice:* The manufacturer recommends 5 ml/L for soil. Since pumice is completely inert (no CEC, zero background nutrients), the ramp must be steeper — the tiny soil nest only feeds the seedling for the first ~2 weeks.
    *   *800ml Reservoir:*
        *   **50%** (~2.0 ml) — Week 3, reservoir activation
        *   **75–100%** (~3.0–4.0 ml) — Week 4–5, stretch
        *   **100%** (~4.0 ml) — Flowering phase
        *   **125%** (~5.0 ml) — Optional peak bloom boost, only if no tip burn
*   **CalMag:** Hy-Pro Terra contains calcium and magnesium, but the manufacturer recommends **Hy-Pro Cal-Mag** supplementation when reusing substrate. Pumice is reused indefinitely — add **0.5–1.0 ml CalMag per liter** to every third reservoir fill to prevent deficiencies.
*   **pH Correction:** **~2.3 ml** Canna pH- Bloom per 800 ml water.
    *   *Target pH:* **5.8** (Hydro standard). The exact amount of pH-Down depends on your tap water and the fertilizer used; test the value after mixing and adjust accordingly.
*   **Mixing Order:** First dissolve the fertilizer (+ CalMag if used) in the water, then adjust the pH.

---

## 2. The Grow Cycle (Timeline)

### Phase 0: Pre-Phase (Germination & Establishment)
*   **Duration:** Approx. 3 to 7 days.
*   **Action:** Soak seed in water for 24 to 36 hours. Then plant in the soil nest and water once with **30 ml** of pH-adjusted water.
*   **Care:** Carefully add **3 ml** with the pipette directly onto the seed spot twice a day (keep moist, do not soak).
* **Light:** Set to **18/6 or 20/4 cycle** for the vegetative phase (see experience table below). The long light period builds a strong root system and canopy before switching to 12/12 at Week 3.
* **Which light duration? (Experience-based)**
    * **18/6 (Standard)** — For compact indica-dominant strains, limited tower height (< 80 cm internal), or when growing in confined spaces. 18 hours is the safe, proven default. The plant gets enough light to build structure without excessive stretch.
    * **20/4 (Aggressive)** — For sativa-dominant or stretchy hybrids where you expect the plant to fill the full tower height (80-100 cm). The extra 2 hours accelerate root development and stem thickness early on, giving the plant more "engine" to pull nutrients during the stretch. Use only if your environment can handle the extra heat and the seedling shows vigorous growth from Day 3 onward.
    * **Dynamic approach (advanced):** Start at 18/6 for Days 0-7, then switch to 20/4 for Days 8-21 if the plant looks healthy and you want maximum vegetative mass before flipping. This avoids stressing a fragile seedling while still maximizing the veg window.
    * **Rule of thumb:** Compact plant → 18/6. Stretchy plant / full tower → 20/4. When in doubt, stick with 18/6 — it never fails.
*   **Fan:** **0% power** (high humidity for the seedling).

### Week 1 (Day 1–7): Establishment
*   **Development:** Cotyledons open, the first true pair of leaves forms.
*   **Watering:** Only drop by drop (pipette) if the seed container is extremely dry. The root actively searches its way down into the moist pumice.
*  **Fan:** **30% power** (high humidity for the seedling).

### Week 2 (Day 8–14): First Flush & Root Stretching
*   **Action (Day 8–10):** Single full watering from above with **800 ml** of pH-adjusted water (without fertilizer) until water runs out the bottom (drain).
*   **Important:** After this, **do not water at all** until the substrate feels significantly lighter. This forces the roots to grow to the bottom of the pot.

### Week 3 (Day 15–21): Activating the Reservoir & Switching to Flower
* **Light Switch:** Switch the light cycle from your vegetative schedule (**18/6 or 20/4**) to **12/12** (12h ON / 12h OFF). This triggers the hormonal transition from vegetative growth to flowering.
*   **The Reservoir Test:** Fill the reservoir to 20–30% with pure, pH-adjusted water.
    *   *Important:* If there is still water from the First Flush (Week 2) in the reservoir, **pour it out completely** before adding the fresh reservoir water. The old flush water may contain unwanted runoff and is not suitable for the wick system.
    *   *Water Freshness:* In the early stages when the seedling consumes very little water, do not let the nutrient solution sit in the reservoir for more than **7 to 10 days** (maximum 14 days) to prevent it from going bad.
*   **Action:** Stop all top-watering. The three wicks now take over the supply.
*   **Nutrients:** The soil nest is nearly depleted by now, and pumice provides nothing. Start the reservoir with a **50% dose** (~2.0 ml Hy-Pro Terra per 800 ml) immediately — not 25%. This avoids a deficiency gap during the transition from soil to hydro feeding.

### Week 4–5 (Day 22–35): Pre-Flowering, Stretch & Flowering Start
*   **Development:** The plant reaches hormonal maturity and begins to stretch suddenly. First white hairs (pistils) appear.
*   **Mark Flowering Day:** Note the exact day the first pistils appear — this is **Day 1 of flowering**! If your grow controller supports switching to a flowering timer, set it to this day. If unsure, assume **Day 30** as a rule of thumb.
*   **Fertilization:** Nutrient demand spikes massively during stretch. Increase to **75–100% of the full dose** (~3.0–4.0 ml Hy-Pro Terra per 800 ml). Start at 3.0 ml and ramp to 4.0 ml by the end of this phase. This prevents the plant from cannibalizing lower leaves, which turn yellow fast in inert media.
*   **Care:** Refill the reservoir regularly. Water consumption increases sharply.

### Flowering Phase (Flower Day 1 to End of Strain's Flowering Time)
*   **Duration:** Depends on the strain. Check the breeder's info (e.g., Purple Bud ~60 days flowering time). **Total grow time ≈ 30 days (pre/veg) + strain's flowering time**.
*   **Development:** Vertical stretch stops after the first half of flowering, focus shifts entirely to bud formation.
*   **Fan:** Increase to **46% power**. As leaves become denser, more airflow is needed to remove moisture and prevent mold.
*   **Fertilization:** Fill the reservoir with the nutrient solution (**~4.0 ml Hy-Pro Terra + ~2.3 ml pH-Down per 800 ml**). If the plant shows no signs of tip burn by mid-flower, an optional peak boost of **~5.0 ml** (125%) can be tested for heavier bud development.
*   **Observation:** If leaves become very dark, reduce the fertilizer dose.

### Final Ripening & Flush (Last 10–14 Days Before Harvest)
*   **Action:** Stop all fertilizer **10 to 14 days before the end of the stated flowering time**. Fill the reservoir only with **pure, pH-adjusted water**.
*   **Goal:** The plant consumes its internal reserves. This ensures a clean taste without harshness.
*   **Example:** For a 60-day flowering strain, begin flushing on flower day 46–50.

---

## 3. Critical Success Factors

*   **No Top-Watering:** Once the wick system is active, never water from above again! This would flush accumulated mineral salts from the surface directly to the roots ("nutrient shock").
*   **pH Stability:** Since pumice has no buffering capacity, a correct pH (approx. 5.8) is vital.
*   **Salt Buildup (Pumice-Specific):** Unlike soil, pumice does not bind or buffer nutrients. Since the wick system feeds continuously (no water-only cycles), mineral salts can accumulate in the pumice over time. Every **2–3 reservoir refills**, do a "mini-flush": fill the reservoir with pure pH-adjusted water only, let the wicks pull it through for 24 hours, then drain and refill with fresh nutrient solution. This prevents EC creep and lockout.
*   **Wick Contact:** Ensure the wicks in the pot have direct contact with the seed container to pull moisture up during the critical initial phase.
*   **Stagnant Reservoir Water (Root Rot Prevention):** Since the GrowTower is a passive wick system without active aeration (like air stones), stagnant water will lose its dissolved oxygen over time. If water is left in the reservoir for too long (especially in the early growth stages when water consumption is very low), it will become anaerobic. This breeds harmful bacteria and pathogens like *Pythium*, leading to **root rot (Wurzelfäule)**, which turns roots brown and slimy and kills the plant.
    *   *Rule of Thumb:* Never let the nutrient solution sit in the reservoir for more than **7 to 10 days (maximum 14 days)**. If it is not consumed by then, pour it out, rinse the reservoir, and refill it with fresh solution. If you notice a sour, swampy smell or cloudy water, replace it immediately.

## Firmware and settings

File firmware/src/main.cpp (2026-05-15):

#include "secrets.h"
#include <Arduino.h>
#include <ArduinoOTA.h>
#include <ESPAsyncWebServer.h>
#include <ESPmDNS.h>
#include <Preferences.h>
#include <WiFi.h>
#include <time.h>

#include "config.h"
#include "frontend.h"
#include "state.h"
#include "webserver.h"


Preferences preferences;
char currentHostname[32] = "growtower";

int fanMinPercent = 0;
int fanMaxPercent = 100;
int lightOnHour = 10;   // One Bud Method only Flower
int lightDuration = 12; // One Bud Method only Flower
bool timerEnabled = true;

bool isLightOn = false;
int currentFanSpeed = 30;
TimezoneMode currentTzMode = TZ_AUTO;

bool isAPMode = false;
unsigned long lastBlinkTime = 0;
char wifiSSID[32] = "";
char wifiPass[64] = "";

PhaseData phases[3] = {{0, false}, {0, false}, {0, false}};
PlantPhase currentPhase = PHASE_NONE;

unsigned long lastWiFiCheck = 0;
bool wasConnected = true;

void loadLogbook();
void saveLogbook();
void addLogEntry(String text);
void deleteLogEntry(int index);
void clearLogbook();
String getLogbookJSON();
void checkWiFi();
void setSystemTime(long epoch);

void setSystemTime(long epoch) {
  struct timeval tv;
  tv.tv_sec = epoch;
  tv.tv_usec = 0;
  settimeofday(&tv, NULL);
  Serial.printf("[TIME] System time set manually to: %ld\n", epoch);
}

void applyTimezone() {
  const char *tz;
  switch (currentTzMode) {
  case TZ_WINTER:
    tz = "CET-1";
    Serial.println("[TIME] Mode: Winter (CET-1)");
    break;
  case TZ_SUMMER:
    tz = "CEST-2";
    Serial.println("[TIME] Mode: Summer (CEST-2)");
    break;
  case TZ_AUTO:
  default:
    tz = TZ_INFO;
    Serial.println("[TIME] Mode: Auto (Europe/Berlin)");
    break;
  }
  configTzTime(tz, NTP_SERVER);
}

AsyncWebServer server(80);

void setup() {
  Serial.begin(115200);
  delay(1000);

  Serial.println("\n");
  Serial.println(
      "╔══════════════════════════════════════════════════════════════╗");
  Serial.println(
      "║                    🌱 GrowTower v3.0                         ║");
  Serial.println(
      "║           Web-Based Cultivation System                       ║");
  Serial.println(
      "╚══════════════════════════════════════════════════════════════╝");
  Serial.println("\n[SYS] System initializing...\n");

  Serial.println("[SYS] Loading configuration from flash...");
  loadSettings();

  Serial.println("[SYS] Initializing light control...");
  pinMode(LIGHT_PIN, OUTPUT);
  setLight(false);

  Serial.println("[SYS] Initializing fan PWM...");
  initPWM();
  setFan(currentFanSpeed);

  Serial.println("[SYS] Initializing WiFi...");
  initWiFi();
  wasConnected = (WiFi.status() == WL_CONNECTED);

  Serial.println("[SYS] Initializing OTA...");
  initOTA();

  Serial.println("[SYS] Initializing Web Server...");
  initWebServer();

  Serial.println("\n[SYS] Initialization complete!");
  printStatus();
  Serial.println("\n[SYS] Ready. Access the controller at: http://" +
                 String(currentHostname) + ".local\n");
}

void loop() {
  ArduinoOTA.handle();

  struct tm timeinfo;
  if (!getLocalTime(&timeinfo)) {
    // No time available -> Blink!
    unsigned long now = millis();
    if (now - lastBlinkTime >= 1000) {
      lastBlinkTime = now;
      setLight(!isLightOn);
      Serial.println("[SYS] WARNING: No time sync! Blinking...");
    }
  } else {
    checkTimer();
  }

  checkWiFi();

  if (Serial.available() > 0) {
    String input = Serial.readStringUntil('\n');
    input.trim();
    if (input.length() > 0) {
      processCommand(input);
    }
  }

  delay(100);
}

void checkWiFi() {
  if (isAPMode)
    return;

  if (WiFi.status() != WL_CONNECTED) {
    if (wasConnected) {
      Serial.println("[WIFI] Connection lost!");
      wasConnected = false;
      lastWiFiCheck = millis();
    }

    unsigned long now = millis();
    if (now - lastWiFiCheck >= WIFI_RECONNECT_INTERVAL) {
      lastWiFiCheck = now;
      Serial.println("[WIFI] Attempting to reconnect...");
      initWiFi();
    }
  } else {
    if (!wasConnected) {
      Serial.printf("[WIFI] Connection restored! IP: %s\n",
                    WiFi.localIP().toString().c_str());
      wasConnected = true;

      // Re-initialize NTP on reconnection
      Serial.println("[NTP] Re-synchronizing time...");
      applyTimezone();
    }
  }
}

void initPWM() {
  ledcSetup(PWM_CHANNEL, PWM_FREQUENCY, PWM_RESOLUTION);
  ledcAttachPin(FAN_PIN, PWM_CHANNEL);
  Serial.printf("[PWM] Initialized: Channel=%d, Freq=%dHz, Resolution=%dbit\n",
                PWM_CHANNEL, PWM_FREQUENCY, PWM_RESOLUTION);
}

void initWiFi() {
  String ssid = String(wifiSSID);
  String pass = String(wifiPass);

  if (ssid == "") {
#ifdef WIFI_SSID
    ssid = WIFI_SSID;
#ifdef WIFI_PASS
    pass = WIFI_PASS;
#endif
#endif
  }

  if (ssid != "") {
    Serial.printf("[WIFI] Connecting to: %s\n", ssid.c_str());
    WiFi.mode(WIFI_STA);
    if (pass != "") {
      WiFi.begin(ssid.c_str(), pass.c_str());
    } else {
      WiFi.begin(ssid.c_str());
    }

    int retries = 0;
    while (WiFi.status() != WL_CONNECTED && retries < 20) {
      delay(500);
      Serial.print(".");
      retries++;
    }
    Serial.println();
  }

  if (WiFi.status() == WL_CONNECTED) {
    Serial.printf("[WIFI] Connected! IP: %s\n",
                  WiFi.localIP().toString().c_str());
    isAPMode = false;
    wasConnected = true;
    Serial.println("[NTP] Initializing time synchronization...");
    applyTimezone();
    printLocalTime();
  } else {
    Serial.println("[WIFI] Connection failed! Starting Fallback AP...");
    WiFi.mode(WIFI_AP);
    WiFi.softAP("GrowTower-Fallback");
    Serial.printf("[WIFI] AP Started: GrowTower-Fallback | IP: %s\n",
                  WiFi.softAPIP().toString().c_str());
    isAPMode = true;
    wasConnected = false;
  }
}

void initOTA() {
  if (WiFi.status() != WL_CONNECTED) {
    Serial.println("[OTA] WiFi not connected, OTA disabled");
    return;
  }

  if (!MDNS.begin(currentHostname)) {
    Serial.println("[OTA] Error setting up mDNS responder!");
    return;
  }
  Serial.printf("[OTA] mDNS responder started: %s.local\n", currentHostname);

  MDNS.addService("http", "tcp", 80);

  ArduinoOTA.setHostname(currentHostname);
  ArduinoOTA.setPort(OTA_PORT);
  ArduinoOTA.setPassword("growtower123");

  ArduinoOTA.onStart([]() {
    String type = ArduinoOTA.getCommand() == U_FLASH ? "sketch" : "filesystem";
    Serial.printf("[OTA] Start updating %s\n", type.c_str());
  });

  ArduinoOTA.onEnd([]() { Serial.println("[OTA] Update complete"); });

  ArduinoOTA.onProgress([](unsigned int progress, unsigned int total) {
    Serial.printf("[OTA] Progress: %u%%\r", (progress / (total / 100)));
  });

  ArduinoOTA.onError([](ota_error_t error) {
    Serial.printf("[OTA] Error[%u]: ", error);
    if (error == OTA_AUTH_ERROR)
      Serial.println("Auth failed");
    else if (error == OTA_BEGIN_ERROR)
      Serial.println("Begin failed");
    else if (error == OTA_CONNECT_ERROR)
      Serial.println("Connect failed");
    else if (error == OTA_RECEIVE_ERROR)
      Serial.println("Receive failed");
    else if (error == OTA_END_ERROR)
      Serial.println("End failed");
  });

  ArduinoOTA.begin();
  Serial.printf("[OTA] Ready on port %d\n", OTA_PORT);
}

String getStatusJSON() {
  struct tm timeinfo;
  bool hasTime = getLocalTime(&timeinfo);

  String json = "{";
  json += "\"light\":" + String(isLightOn ? "true" : "false") + ",";
  json += "\"fan\":" + String(currentFanSpeed) + ",";
  json += "\"fanMin\":" + String(fanMinPercent) + ",";
  json += "\"fanMax\":" + String(fanMaxPercent) + ",";
  json += "\"lightOn\":" + String(lightOnHour) + ",";
  json += "\"lightDuration\":" + String(lightDuration) + ",";
  json += "\"timerEnabled\":" + String(timerEnabled ? "true" : "false") + ",";
  json += "\"tzMode\":" + String((int)currentTzMode) + ",";
  json += "\"hostname\":\"" + String(currentHostname) + "\",";
  json += "\"ip\":\"" + WiFi.localIP().toString() + "\",";
  json += "\"wifiConnected\":" +
          String(WiFi.status() == WL_CONNECTED ? "true" : "false") + ",";
  json += "\"hasTime\":" + String(hasTime ? "true" : "false");
  if (hasTime) {
    char timeStr[25];
    strftime(timeStr, sizeof(timeStr), "%H:%M:%S", &timeinfo);
    json += ",\"currentTime\":\"" + String(timeStr) + "\"";
  }
  json += "," + getPhaseJSON();
  json += "}";
  return json;
}

void loadSettings() {
  preferences.begin("growtower", true);

  fanMinPercent = preferences.getInt("fanMin", 0);
  fanMaxPercent = preferences.getInt("fanMax", 100);
  currentFanSpeed = preferences.getInt("fanSpeed", 30);
  lightOnHour = preferences.getInt("onHour", 10);
  lightDuration = preferences.getInt("duration", 12);
  timerEnabled = preferences.getBool("timerEnabled", true);
  currentTzMode = (TimezoneMode)preferences.getInt("tzMode", (int)TZ_AUTO);

  String savedHostname = preferences.getString("hostname", DEFAULT_HOSTNAME);
  strncpy(currentHostname, savedHostname.c_str(), sizeof(currentHostname) - 1);
  currentHostname[sizeof(currentHostname) - 1] = '\0';

  String savedSSID = preferences.getString("ssid", "");
  String savedPass = preferences.getString("pass", "");
  strncpy(wifiSSID, savedSSID.c_str(), sizeof(wifiSSID) - 1);
  strncpy(wifiPass, savedPass.c_str(), sizeof(wifiPass) - 1);

  preferences.end();

  loadPhaseData();
  loadLogbook();

  Serial.printf("[CONFIG] Loaded: FanMin=%d%%, FanMax=%d%%, FanSpeed=%d%%, "
                "LightOn=%d:00, Duration=%dh, "
                "Hostname=%s, TzMode=%d\n",
                fanMinPercent, fanMaxPercent, currentFanSpeed, lightOnHour,
                lightDuration, currentHostname, (int)currentTzMode);
}

void saveWiFiCredentials(const char *ssid, const char *pass) {
  preferences.begin("growtower", false);
  preferences.putString("ssid", ssid);
  preferences.putString("pass", pass);
  preferences.end();

  strncpy(wifiSSID, ssid, sizeof(wifiSSID) - 1);
  strncpy(wifiPass, pass, sizeof(wifiPass) - 1);

  Serial.println("[CONFIG] WiFi credentials saved. Restarting...");
  delay(1000);
  ESP.restart();
}

void saveFanSpeed(int percent) {
  if (percent < 0)
    percent = 0;
  if (percent > 100)
    percent = 100;

  currentFanSpeed = percent;
  preferences.begin("growtower", false);
  preferences.putInt("fanSpeed", currentFanSpeed);
  preferences.end();

  Serial.printf("[CONFIG] Fan Speed saved: %d%%\n", currentFanSpeed);
  setFan(currentFanSpeed);
}

void saveFanMin(int minVal) {
  if (minVal < 0)
    minVal = 0;
  if (minVal > 100)
    minVal = 100;

  fanMinPercent = minVal;
  preferences.begin("growtower", false);
  preferences.putInt("fanMin", fanMinPercent);
  preferences.end();

  Serial.printf("[CONFIG] Fan Min saved: %d%%\n", fanMinPercent);
  setFan(currentFanSpeed);
}

void saveFanMax(int maxVal) {
  if (maxVal < 0)
    maxVal = 0;
  if (maxVal > 100)
    maxVal = 100;

  fanMaxPercent = maxVal;
  preferences.begin("growtower", false);
  preferences.putInt("fanMax", fanMaxPercent);
  preferences.end();

  Serial.printf("[CONFIG] Fan Max saved: %d%%\n", fanMaxPercent);
  setFan(currentFanSpeed);
}

void saveLightOnHour(int hour) {
  if (hour < 0)
    hour = 0;
  if (hour > 23)
    hour = 23;

  lightOnHour = hour;
  preferences.begin("growtower", false);
  preferences.putInt("onHour", lightOnHour);
  preferences.end();

  Serial.printf("[CONFIG] Light On Hour saved: %d:00\n", lightOnHour);
  checkTimer();
}

void saveLightDuration(int hours) {
  if (hours < 1)
    hours = 1;
  if (hours > 24)
    hours = 24;

  lightDuration = hours;
  preferences.begin("growtower", false);
  preferences.putInt("duration", lightDuration);
  preferences.end();

  Serial.printf("[CONFIG] Light Duration saved: %dh\n", lightDuration);
  checkTimer();
}

void saveTimerEnabled(bool enabled) {
  timerEnabled = enabled;
  preferences.begin("growtower", false);
  preferences.putBool("timerEnabled", timerEnabled);
  preferences.end();

  Serial.printf("[CONFIG] Timer enabled: %s\n",
                timerEnabled ? "true" : "false");
  checkTimer();
}

void saveTzMode(TimezoneMode mode) {
  currentTzMode = mode;
  preferences.begin("growtower", false);
  preferences.putInt("tzMode", (int)currentTzMode);
  preferences.end();

  Serial.printf("[CONFIG] Timezone mode saved: %d\n", (int)currentTzMode);
  applyTimezone();
}

void resetAllSettings() {
  Serial.println("[SYS] Resetting all settings to defaults...");
  preferences.begin("growtower", false);
  preferences.clear();
  preferences.end();

  phases[PHASE_SEEDLING].startTime = 0;
  phases[PHASE_SEEDLING].active = false;
  phases[PHASE_VEG].startTime = 0;
  phases[PHASE_VEG].active = false;
  phases[PHASE_FLOWER].startTime = 0;
  phases[PHASE_FLOWER].active = false;
  currentPhase = PHASE_NONE;
  savePhaseData();
  clearLogbook();

  Serial.println("[SYS] Settings cleared. Rebooting...");
  delay(1000);
  ESP.restart();
}

void saveHostname(const char *hostname) {
  preferences.begin("growtower", false);
  preferences.putString("hostname", hostname);
  preferences.end();

  strncpy(currentHostname, hostname, sizeof(currentHostname) - 1);
  currentHostname[sizeof(currentHostname) - 1] = '\0';

  Serial.printf("[CONFIG] Hostname saved: %s\n", currentHostname);
}

void setLight(bool on) {
  if (on) {
    digitalWrite(LIGHT_PIN, HIGH);
    Serial.println("[LIGHT] State: ON");
  } else {
    digitalWrite(LIGHT_PIN, LOW);
    Serial.println("[LIGHT] State: OFF");
  }
  isLightOn = on;
}

void setFan(int percent) {
  if (percent < 0)
    percent = 0;
  if (percent > 100)
    percent = 100;

  currentFanSpeed = percent;
  int dutyCycle = 0;

  if (percent == 0) {
    dutyCycle = 0;
  } else {
    int effectiveMin = fanMinPercent;
    int effectiveMax = fanMaxPercent;
    if (effectiveMin > effectiveMax) {
      effectiveMin = effectiveMax;
    }

    long mappedPercent = map(percent, 1, 100, effectiveMin, effectiveMax);
    dutyCycle =
        map(mappedPercent, 0, 100, HARDWARE_FAN_MIN_DUTY, MAX_DUTY_CYCLE);
  }

  ledcWrite(PWM_CHANNEL, dutyCycle);

  Serial.printf(
      "[FAN] Speed: %d%% (Effective Range: %d%%-%d%%, Duty: %d/255)\n", percent,
      fanMinPercent, fanMaxPercent, dutyCycle);
}

void checkTimer() {
  if (!timerEnabled) {
    return;
  }

  struct tm timeinfo;
  if (!getLocalTime(&timeinfo)) {
    return;
  }

  int currentHour = timeinfo.tm_hour;
  bool shouldBeOn = false;

  int lightOffHour = lightOnHour + lightDuration;
  if (lightOffHour >= 24)
    lightOffHour -= 24;

  if (lightOnHour > lightOffHour) {
    shouldBeOn = (currentHour >= lightOnHour || currentHour < lightOffHour);
  } else {
    shouldBeOn = (currentHour >= lightOnHour && currentHour < lightOffHour);
  }

  if (shouldBeOn != isLightOn) {
    Serial.printf("[TIMER] Time: %02d:%02d | Light: %02d:00-%02d:00 | "
                  "Auto-switching light %s\n",
                  currentHour, timeinfo.tm_min, lightOnHour, lightOffHour,
                  shouldBeOn ? "ON" : "OFF");
    setLight(shouldBeOn);
  }
}

void printLocalTime() {
  struct tm timeinfo;
  if (!getLocalTime(&timeinfo)) {
    Serial.println("[TIME] Failed to get time from NTP");
    return;
  }

  char timeString[50];
  strftime(timeString, sizeof(timeString), "%A, %B %d %Y %H:%M:%S", &timeinfo);
  Serial.printf("[TIME] Current: %s\n", timeString);
}

void printStatus() {
  int lightOffHour = lightOnHour + lightDuration;
  if (lightOffHour >= 24)
    lightOffHour -= 24;
  Serial.println("\n═══════════════ CURRENT STATUS ═══════════════");
  Serial.printf("  Light:        %s\n", isLightOn ? "ON ✓" : "OFF ✗");
  Serial.printf("  Fan Speed:    %d%%\n", currentFanSpeed);
  Serial.printf("  Fan Range:    %d%% - %d%%\n", fanMinPercent, fanMaxPercent);
  Serial.printf("  Light Timer:  %02d:00 - %02d:00 (%dh)\n", lightOnHour,
                lightOffHour, lightDuration);
  Serial.printf("  Hostname:     %s.local\n", currentHostname);
  Serial.printf("  IP Address:   %s\n", WiFi.localIP().toString().c_str());
  Serial.printf("  Web Server:   %s\n",
                WiFi.status() == WL_CONNECTED ? "Running ✓" : "Disabled ✗");
  Serial.println("═══════════════════════════════════════════════\n");
}

void processCommand(String command) {
  command.trim();
  command.toUpperCase();

  Serial.printf("[CMD] Received: '%s'\n", command.c_str());

  if (command == "HELP" || command == "?") {
    Serial.println("\n╔════════════════════════════════════════════════╗");
    Serial.println("║              AVAILABLE COMMANDS                ║");
    Serial.println("╠════════════════════════════════════════════════╣");
    Serial.println("║  ON              - Turn light ON               ║");
    Serial.println("║  OFF             - Turn light OFF              ║");
    Serial.println("║  FAN <0-100>     - Set fan speed (percent)    ║");
    Serial.println("║  FANMIN <0-100>  - Set fan minimum speed      ║");
    Serial.println("║  FANMAX <0-100>  - Set fan maximum speed      ║");
    Serial.println("║  LIGHTON <0-23>  - Set light ON hour           ║");
    Serial.println("║  LIGHTTIME <1-24>- Set light duration (hours) ║");
    Serial.println("║  HOST <name>     - Set hostname               ║");
    Serial.println("║  TIME            - Show current time          ║");
    Serial.println("║  STATUS          - Show system status         ║");
    Serial.println("║  RESET           - Reset all settings         ║");
    Serial.println("║  HELP            - Show this help             ║");
    Serial.println("╚════════════════════════════════════════════════╝\n");
  } else if (command == "ON") {
    setLight(true);
  } else if (command == "OFF") {
    setLight(false);
  } else if (command.startsWith("FAN ")) {
    String valueStr = command.substring(4);
    valueStr.trim();
    int value = valueStr.toInt();
    saveFanSpeed(value);
  } else if (command.startsWith("FANMIN ")) {
    String valueStr = command.substring(7);
    valueStr.trim();
    int value = valueStr.toInt();
    saveFanMin(value);
  } else if (command.startsWith("FANMAX ")) {
    String valueStr = command.substring(7);
    valueStr.trim();
    int value = valueStr.toInt();
    saveFanMax(value);
  } else if (command.startsWith("LIGHTON ")) {
    String valueStr = command.substring(8);
    valueStr.trim();
    int value = valueStr.toInt();
    saveLightOnHour(value);
  } else if (command.startsWith("LIGHTTIME ")) {
    String valueStr = command.substring(10);
    valueStr.trim();
    int value = valueStr.toInt();
    saveLightDuration(value);
  } else if (command.startsWith("HOST ")) {
    String valueStr = command.substring(5);
    valueStr.trim();
    valueStr.toLowerCase();
    if (valueStr.length() > 0 && valueStr.length() < 32) {
      saveHostname(valueStr.c_str());
      Serial.println("[CMD] Hostname saved. Restart to apply changes.");
    } else {
      Serial.println("[CMD] Invalid hostname (1-31 chars)");
    }
  } else if (command == "TIME") {
    printLocalTime();
  } else if (command == "STATUS") {
    printStatus();
  } else if (command == "RESET") {
    resetAllSettings();
  } else {
    Serial.printf("[CMD] Unknown command: '%s'\n", command.c_str());
    Serial.println("[CMD] Type 'HELP' for available commands");
  }
}

void loadPhaseData() {
  preferences.begin("growtower", true);

  phases[PHASE_SEEDLING].startTime = preferences.getLong("seedlingStart", 0);
  phases[PHASE_VEG].startTime = preferences.getLong("vegStart", 0);
  phases[PHASE_FLOWER].startTime = preferences.getLong("flowerStart", 0);

  phases[PHASE_SEEDLING].active = preferences.getBool("seedlingActive", false);
  phases[PHASE_VEG].active = preferences.getBool("vegActive", false);
  phases[PHASE_FLOWER].active = preferences.getBool("flowerActive", false);

  preferences.end();

  currentPhase = PHASE_NONE;
  if (phases[PHASE_SEEDLING].active)
    currentPhase = PHASE_SEEDLING;
  else if (phases[PHASE_VEG].active)
    currentPhase = PHASE_VEG;
  else if (phases[PHASE_FLOWER].active)
    currentPhase = PHASE_FLOWER;

  Serial.printf("[PHASE] Loaded: Seedling=%d, Veg=%d, Flower=%d, Current=%d\n",
                phases[PHASE_SEEDLING].active ? 1 : 0,
                phases[PHASE_VEG].active ? 1 : 0,
                phases[PHASE_FLOWER].active ? 1 : 0, currentPhase);
}

void savePhaseData() {
  preferences.begin("growtower", false);

  preferences.putLong("seedlingStart", phases[PHASE_SEEDLING].startTime);
  preferences.putLong("vegStart", phases[PHASE_VEG].startTime);
  preferences.putLong("flowerStart", phases[PHASE_FLOWER].startTime);

  preferences.putBool("seedlingActive", phases[PHASE_SEEDLING].active);
  preferences.putBool("vegActive", phases[PHASE_VEG].active);
  preferences.putBool("flowerActive", phases[PHASE_FLOWER].active);

  preferences.end();
}

void setPhase(PlantPhase phase) {
  struct tm timeinfo;
  if (!getLocalTime(&timeinfo)) {
    Serial.println("[PHASE] Cannot set phase: NTP time not available");
    return;
  }

  time_t now = mktime(&timeinfo);

  if (phase == PHASE_NONE) {
    phases[PHASE_SEEDLING].active = false;
    phases[PHASE_VEG].active = false;
    phases[PHASE_FLOWER].active = false;
    currentPhase = PHASE_NONE;
    Serial.println("[PHASE] All phases reset");
  } else {
    phases[PHASE_SEEDLING].active = (phase == PHASE_SEEDLING);
    phases[PHASE_VEG].active = (phase == PHASE_VEG);
    phases[PHASE_FLOWER].active = (phase == PHASE_FLOWER);

    if (phase == PHASE_SEEDLING && phases[PHASE_SEEDLING].startTime == 0) {
      phases[PHASE_SEEDLING].startTime = now;
    } else if (phase == PHASE_VEG && phases[PHASE_VEG].startTime == 0) {
      phases[PHASE_VEG].startTime = now;
    } else if (phase == PHASE_FLOWER && phases[PHASE_FLOWER].startTime == 0) {
      phases[PHASE_FLOWER].startTime = now;
    }

    currentPhase = phase;

    const char *phaseNames[] = {"None", "Seedling", "Veg", "Flower"};
    Serial.printf("[PHASE] Set to: %s\n", phaseNames[phase]);
  }

  savePhaseData();
}
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

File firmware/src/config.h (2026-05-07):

#ifndef CONFIG_H
#define CONFIG_H

#define LIGHT_PIN D1
#define FAN_PIN D2

const int PWM_FREQUENCY = 25000;
const int PWM_RESOLUTION = 8;
const int PWM_CHANNEL = 0;
const int MAX_DUTY_CYCLE = 255;
const int HARDWARE_FAN_MIN_DUTY = 13;

const uint16_t OTA_PORT = 3232;

const char *DEFAULT_HOSTNAME = "growtower";

const unsigned long WIFI_RECONNECT_INTERVAL = 30000; // 30 seconds

const char *NTP_SERVER = "pool.ntp.org";
const char *TZ_INFO = "CET-1CEST,M3.5.0,M10.5.0/3"; // Europe/Berlin

#endif

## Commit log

2025-12-26 feat: print files
    [Fan Adapter.stl, Filter Housing.stl, Inner Shell.stl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]
2025-12-28 feat: better sieve printing
2026-01-01 fix: pins and control
    [main.cpp]
2026-01-01 new adapter
    [Fan Adapter.stl]
2026-01-01 adnroid BLE app
    [top_app_bar.xml]
2026-01-22 refactor: improve ble stability and frontend ui with log terminal
    [main.cpp]
2026-01-24 docs: add current experiments section to README (Stress Killer CBD & One-Bud
2026-02-01 Add OpenCode agents and skills for GrowTower project
    - Add AGENTS.md with 4 specialized agents:
    * firmware-agent: ESP32 firmware development
    * android-agent: Kotlin/Jetpack Compose development
    * hardware-agent: 3D printing and hardware assembly
    * protocol-agent: BLE protocol definition
    - Add 8 reusable skills in .opencode/skills/:
    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
2026-02-05 Add OTA support with mDNS to firmware
    - Add ArduinoOTA library dependency
    - Create main_ota environment for OTA uploads via mDNS
    - Implement OTA initialization with mDNS responder
    - Add ArduinoOTA event handlers for start, progress, end, and error
    - Handle OTA updates in main loop
    - Add .env.example file for WiFi credentials documentation
    OTA is reachable at growtower.local:3232 when connected to WiFi
    [main.cpp]
2026-02-05 Remove old Android app and BleApp library
    - Delete entire android/ directory (old Android app)
    - Delete firmware/lib/BleApp/ (replaced by GrowTowerBLE)
    - Add new web-app and web-controller directories
    - Update VS Code settings
    [top_app_bar.xml]
2026-02-10 Replace BLE with web server and update documentation
    - Remove BLE library and all BLE functionality
    - Add AsyncWebServer for HTTP-based control
    - Add REST API endpoints for all controls
    - Add embedded HTML/JS frontend served from ESP32
    - Add configurable hostname support (default: growtower.local)
    - Update main README with web controller features
    - Update firmware README with complete web interface docs
    - Remove web-app directory (no longer needed)
    The device is now accessible via http://growtower.local with full
    web-based control, REST API, and automatic timer functionality.
    [main.cpp]
2026-02-13 docs: add plant pot printing instructions with slicer cutting method
2026-02-13 docs: update plant pot image captions and STL file
    [plant pot.stl]
2026-02-14 improvement: plant pot printable
    [plant pot.stl]
2026-02-15 Update current grow status with detailed observations
    Add current state of Stress Killer CBD grow:
    - Yellow leaves due to root moisture blocking nutrient uptake
    - Wick system with no-name soil (no perlite) caused the issue
    - Buds are large and dense despite problems
    - Plant is bushy at bottom
    - Expected harvest: March 2026
2026-02-19 Add 3D printing instructions for Reservoir 850 Vase with vase mode, bottom layers, pattern design, layer height and flow rate recommendations
2026-02-19 Add troubleshooting tips for reservoir leaks including water test and soldering iron welding technique
2026-02-19 Add ironing and infill/wall overlap tips for reservoir printing
2026-02-19 Move 3D printing instructions to separate stls/README.md with detailed OrcaSlicer overlap settings
2026-02-20 improve: print files
    [Internal Sieve.stl, plant pot.stl]
2026-02-20 stl update
    [Inner Shell.stl]
2026-02-21 feat: add plant phase tracking with persistent storage
    - Add phase tracking (seedling, veg, flower) with NTP time sync
    - Store phase start times in ESP32 preferences (persistent)
    - Add HTTP API endpoints for phase management
    - Add plant tracker UI to embedded web interface
    - Show days per phase and total plant age
    - Allow resetting individual phases or all phases
    [main.cpp]
2026-02-21 feat: improve phase tracker UI with visual feedback
    - Add active/inactive button states (transparent vs glowing)
    - Toggle phase by clicking active button again
    - Show current phase clearly with color and shadow effects
2026-02-21 Add material recommendations and light-proofing instructions for 3D printing
2026-02-21 feat: add timer toggle, permanent settings storage, and factory reset
    - Add timerEnabled flag to allow disabling automatic light timer
    - Settings now persist permanently in flash storage
    - Add /api/timerenable endpoint for toggling timer
    - Add /api/reset endpoint for factory reset functionality
    - Add UI toggle switch for timer on/off
    - Add 'Werkseinstellungen' reset button in frontend
    [main.cpp, webserver.h]
2026-02-21 stl orientation
    [Fan Adapter.stl, Inner Shell.stl, Outer Shell Bottom.stl]
2026-02-21 feat: add logbook feature for grow tracking
    - Add persistent logbook storage on ESP32 (max 50 entries, 200 chars each)
    - Add POST-based API endpoints for add/delete/clear operations
    - Implement large textarea input in frontend
    - Escape special characters in JSON storage
    - Logbook is cleared on factory reset
    [main.cpp, webserver.h]
2026-02-22 controller case stl
    [Controller Case.stl, Controller Cover.stl]
2026-02-24 Add detailed 3D printing assembly instructions for plant pot and outer shell
2026-02-24 little bit wider
    [Shell Connector.stl]
2026-02-24 Add vase mode printing option for outer shell
2026-02-24 Move 3D printing images to stls/README and consolidate instructions
2026-02-25 Refactor light timer: use duration instead of off-time, translate UI to English
    - Light timer now accepts start time + duration (hours) instead of start/end time
    - Frontend UI completely translated to English
    - Updated AGENTS.md to remove outdated BLE/web-app references
    - API endpoint /api/timer now uses 'duration' param instead of 'off'
    - Serial command LIGHTTIME replaces LIGHTOFF
    [main.cpp, webserver.h]
2026-02-26 Add documentation for the new dryer module (STL)
    [Dryer Module.stl]
2026-03-08 improvement: stability
    [Filter Housing.stl]
2026-03-12 fix: resolve light timer issue by implementing proper DST/timezone handling
    [config.h, main.cpp]
2026-03-12 bigger hole for usb port
    [Controller Case.stl]
2026-05-01 feat: implement persistent fan speed storage in firmware
    This update ensures that the fan speed set via the web interface or serial command is saved to the ESP32's flash memory (Preferences) and restored after a reboot. Also includes documentation updates for Test #3 and BOM.
    [main.cpp, webserver.h]
2026-05-01 docs: add precise dosage recommendations and pipettes to BOM
    Updated pH-Down dosage to 2.3ml/800ml and Fertilizer to 1.8ml/800ml based on user experience. Added pipettes to the bill of materials for precision.
2026-05-01 docs: create comprehensive GROW_GUIDE.md for wick system
    Added a detailed English guide for the hydroponic and hybrid wick system, including dosage recommendations, assembly instructions, and the 12/12 One-Bud timeplan.
2026-05-01 docs: create comprehensive English GROW_GUIDE.md for wick system
    Added detailed instructions for the 12/12 One-Bud method, including dosage recommendations, wick installation, fan settings, and the final ripening/flushing phase.
2026-05-01 docs: GROW_GUIDE.md basierend auf neuem Zeitplan und Lüftereinstellungen aktualisiert
2026-05-01 docs: GROW_GUIDE.md auf Bimsstein-Substrat, 3 Dochte und 800ml Dosierung angepasst
2026-05-01 docs: GROW_GUIDE.md ins Englische übersetzt und finalisiert
2026-05-01 docs: README.md bereinigt und Verweis auf GROW_GUIDE.md hinzugefügt
2026-05-01 docs: Steinwolle aus BOM.md entfernt
2026-05-01 docs: Perlite aus BOM.md entfernt
2026-05-01 docs: Gesamtpreis in BOM.md aktualisiert
2026-05-01 docs: Kostenaufteilung in BOM.md präzisiert
2026-05-07 fix: show phase days and total days for inactive phases
    Previously, getPhaseDays() checked the active flag which caused seedling
    days and total days to show as 0 when switching to another phase (e.g.,
    flower). Now it only checks if startTime is set, so days are correctly
    displayed for all tracked phases regardless of which phase is currently
    active.
    [main.cpp]
2026-05-07 docs: update fan power settings in GROW_GUIDE.md
    Set seedling fan to 0% initially, then 30% from week 1 onwards.
    Also add new text document.
2026-05-07 feat: enable OTA support with dedicated partition table
    - Replace huge_app.csv with partitions_ota.csv for OTA support
    - Add OTA password configuration via secrets.h
    - Remove duplicate OTA_PASSWORD from config.h
    [partitions_ota.csv]
2026-05-07 fix: align factory partition to 64KB boundary in OTA table
    [partitions_ota.csv]
2026-05-07 fix: correct partition sizes to fit 4MB flash
    - Reduce app partitions from 0x1E0000 to 0x100000 (1MB each)
    - Total flash usage now fits within 4MB
    [partitions_ota.csv]
2026-05-07 Revert "feat: enable OTA support with dedicated partition table"
    This reverts commit a97a802c0c96e562306066ac5fabac6075c7efdc.
    [partitions_ota.csv]
2026-05-12 fix(grow-guide): align flowering timeline with strain-specific flowering time
    - Week 4-5: Add note to mark flowering day 1 when first pistils appear
    - Replace fixed Week 6-8 flowering block with strain-relative flowering phase
    - Add rule of thumb: total grow time ≈ 30 days + breeder's flowering time
    - Change final flush from fixed 'Week 9' to last 10-14 days before strain's end
    - Include example calculation for 60-day flowering strain
2026-05-15 feat(firmware): add WiFi AP fallback and visual connection feedback
    - Implement 1s blinking of main light when time sync is missing
    - Add WiFi Access Point fallback ('GrowTower-Fallback') if connection fails
    - Add manual time synchronization from browser via web interface
    - Implement WiFi credential storage and configuration via web interface
    - Update README with troubleshooting instructions for offline mode
    [main.cpp, webserver.h]
2026-06-04 docs: add printable grow protocol and logbook
2026-06-04 docs: translate grow protocol and logbook to English
    [Filter Housing.stl]
2026-06-13 Switch fertilizer from Compo Grow Blüte to Hy-Pro Terra
    - Hy-Pro Terra is a complete 1-component nutrient for both growth and
    flowering, ideal for inert substrates like pumice
    - Updated dosing: 5ml/L manufacturer recommendation, translated to
    800ml reservoir (4.0ml / 2.0ml / 1.0ml for 100%/50%/25% strength)
    - Reservoir now gets 25% dose immediately when activated (Week 3)
    since pumice provides zero nutrients unlike soil
    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
2026-06-13 Validate guide for pure pumice + Rockwool setup (no soil)
    - Swap seed container recommendation: Rockwool preferred over soil
    - Clarify cotyledons feed seedling for first 7-10 days (no early nutrients needed)
    - Add CalMag note for RO/soft water users
    - BOM: add Rockwool starter plugs, mark soil as optional
    - BOM: update pumice description to main medium (not just drainage)
    - Phase 0: specify Rockwool with no-fertilizer rationale
2026-06-13 Adjust Hy-Pro Terra dosing for pure pumice (no soil buffering)
    - Steeper ramp: 50% start (Week 3) instead of 25% — soil nest depleted by day 15-21
    - Stretch: 75-100% (3.0-4.0ml) instead of 50% — max nutrient demand in inert media
    - Flower: keep 100% with optional 125% peak boost (5.0ml)
    - Add CalMag supplement (every 3rd refill) per manufacturer recommendation
    - Add mini-flush routine every 2-3 refills to prevent salt buildup in pumice
    - BOM: add CalMag, update pumice/soil descriptions for current setup
2026-06-13 Add Earth Nest preparation steps to grow guide
    Step-by-step instructions for creating the soil nest:
    - Pumice fill level, cavity dimensions (5cm x 3cm)
    - Wick contact verification
    - Soil amount (~50-70ml), pre-watering (20ml pH 5.8)
    - Seed planting depth (0.5-1cm)
2026-06-15 Update grow plan: 18/6 veg lighting until Week 3, then switch to 12/12 with reservoir activation
